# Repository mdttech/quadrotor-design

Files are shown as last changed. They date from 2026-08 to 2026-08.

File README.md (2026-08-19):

# 🚁 Weight Optimized Quadrotor Design
## Design, Optimization, and Fabrication of a Quadrotor







**Conceptual design, optimization, and fabrication of a 300 g payload / 20 min endurance quadrotor**

A MATLAB sizing tool built on Blade Element Momentum Theory coupled to empirical component-weight regressions, taken from mission requirements through parametric optimization, hardware selection, CAD, fabrication, and bench validation.

Course project — AE630, Autonomous Unmanned Aerial Systems.

**Supervisor:** Prof. Abhishek, 
Department of Aerospace Engineering, Helicopter and VTOL Laboratory
Indian Institute of Technology Kanpur, Kanpur 208016, India

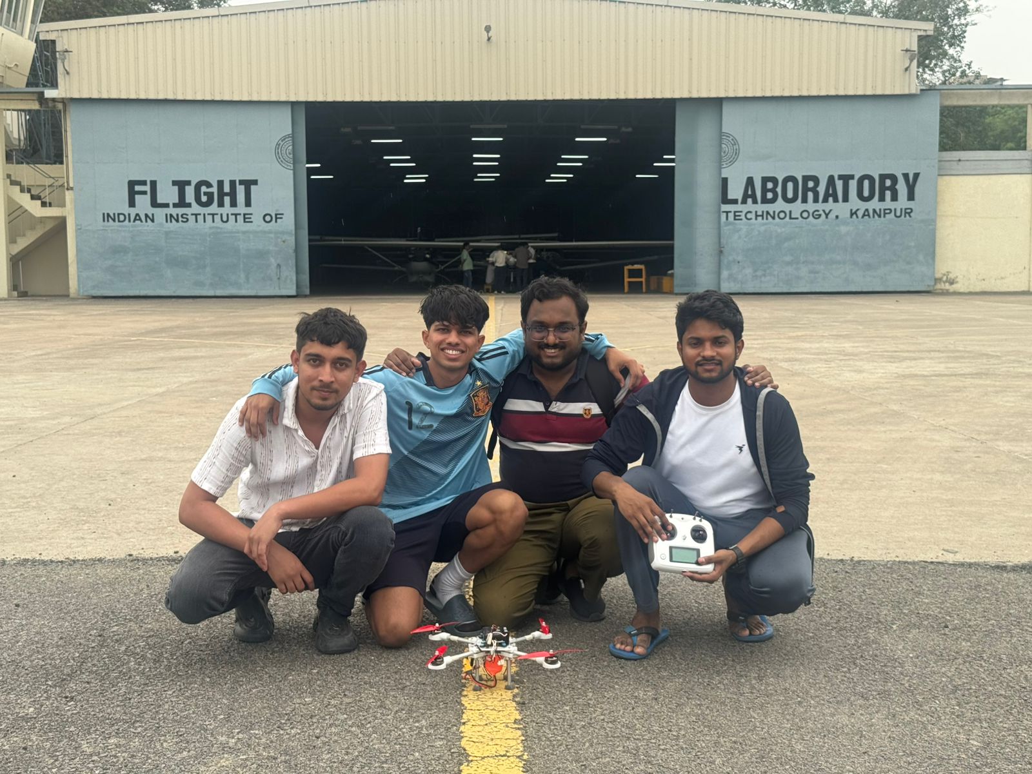
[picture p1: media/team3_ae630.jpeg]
Quadrotor hover test


---

## 🛩️ Mission

| Requirement | Value |
|---|---|
| Payload | 300 g |
| Hover endurance | 20 min |
| Conditions | Sea level, ρ = 1.225 kg/m³ |
| Rotors | Fixed pitch, constant chord |
| Twist distribution | θ(r) = θ₀ − 17r (deg) |
| Target disc loading | 40–90 N/m² |
| Motor efficiency | η_m = 0.80 |

---

## ⚙️ Approach

The design closes on gross takeoff weight through a fixed-point iteration. Every component mass depends on power, power depends on thrust, and thrust depends on the weight you are trying to find — so the loop is run to convergence for every candidate configuration in a parametric sweep.

```
        ┌─────────────────────────────────────────┐
        │  GTOW guess = 3 × payload = 900 g       │
        └────────────────────┬────────────────────┘
                             ▼
              T_hover = W/4  ·  T_design = 2·T_hover
                             ▼
              ┌──────────────────────────────┐
              │  BEMT solver                 │
              │  → C_T, C_P, Ω, P_hover      │
              └──────────────┬───────────────┘
                             ▼
              Battery energy = P_elec × endurance
                             ▼
        ┌─────────────────────────────────────────┐
        │  Empirical weight regressions           │
        │  rotor · motor · ESC · battery · frame  │
        └────────────────────┬────────────────────┘
                             ▼
                  GTOW_new = Σ components
                             ▼
              |ΔW| < 5 g ?  ──no──► relax & repeat
                             │yes
                             ▼
                       converged design
```

**Key modeling note.** With fixed-pitch blades and a linear lift-curve slope, C_T is a property of blade geometry alone and does not vary with rotor speed. This lets the BEMT solver run **once** per geometry at a reference RPM; hover conditions then follow analytically from T ∝ Ω² and P ∝ Ω³. That is what makes a full six-dimensional sweep tractable — thousands of candidate designs converge in seconds instead of hours.

---

## 📐 Design space

Six parameters were swept, with the loop run to convergence at every point:

| Parameter | Range |
|---|---|
| Rotor radius | 0.09 – 0.25 m |
| Root pitch θ₀ | 18° – 26° |
| Aspect ratio (R/c) | 6 – 16 |
| Blades per rotor | 2, 3, 4 |
| Battery cells | 3S, 4S, 6S |
| Motor Kv | 1000 – 3000 |

Note that solidity is **not** independent: σ = N_b·c/πR and AR = R/c give σ = N_b/(π·AR). Only two of the three may be chosen freely.

### Candidate configurations

| | Config 1 | Config 2 | Config 3 |
|---|---|---|---|
| Radius (m) | 0.09 | 0.09 | 0.09 |
| θ₀ (deg) | 26 | 20 | 22 |
| Aspect ratio | 6 | 9 | 8 |
| Blades | 2 | 2 | 2 |
| Cells | 3S | 4S | 4S |
| **GTOW (kg)** | **0.816** | **1.257** | **0.998** |
| Battery (kg) | 0.164 | 0.399 | 0.253 |
| Frame (kg) | 0.225 | 0.338 | 0.274 |
| Hover RPM | 7 849 | 16 717 | 12 157 |
| Kv | 3000 | 1800 | 1300 |
| P_max/motor (W) | 47.3 | 117.9 | 72.3 |

**Config 1** is the mathematical optimum and physically unbuildable — a 12 g motor lacks the stator volume to drive a 7-inch propeller without thermal failure. **Config 2** trades into a punishing 16 700 RPM hover. 
**Config 3** is the realistic middle ground and became the basis for hardware selection.

---

## 🔧 As-built vehicle

Component availability drove the final build away from the theoretical optimum.

| Component | Selection | Qty | Mass |
|---|---|---|---|
| Motor | Emax ECOII-2807, 1300 Kv | 4 | 216 g |
| Propeller | Gemfan Flash 7042 (7.0 × 4.2) | 4 | 24 g |
| ESC | Holybro Tekko32 F4 4-in-1, 50 A | 1 | 13.8 g |
| Battery | Molicel INR21700-P45B 4S1P, 4500 mAh | 1 | 313 g |
| Frame | Custom, aluminium tube arms | 1 | 220 g |
| Avionics & wiring | Pixhawk, GPS, harness | — | 150 g |
| Payload | — | — | 300 g |
| **All-up weight(without payload)** | | | **≈ 937 g** |
| **All-up weight(with payload)** | | | **≈ 1237 g** |

Frame: symmetric X configuration, 3 mm sandwich plates with integrated arm clamps, 12 mm OD aluminium tube arms, gusseted motor mounts. Load path runs motor → mount → arm → clamp → base plate → centre structure.

---

## 📊 Results

Bench thrust testing against the built vehicle:

| Quantity | Predicted (Config 3) | Measured |
|---|---|---|
| Hover efficiency | ≈ 9.8 g/W | 5.41 g/W |
| Hover RPM | 12 157 | 8 440 |
| Hover power (total) | ≈ 102 W | ≈ 228 W |
| Endurance | 20+ min | **≈ 15 min** |

**The vehicle did not meet the 20-minute requirement, and the gap is instructive.**

Three causes account for most of it:

1. **Blade geometry mismatch.** Config 3 models AR = 8 at R = 0.09 m, giving an 11.25 mm chord and σ = 0.080. The Gemfan 7042 actually fitted has roughly a 15–18 mm chord, σ ≈ 0.13. A narrower modeled blade needs higher RPM for the same thrust — which is exactly the 12 157 vs 8 440 RPM discrepancy.

2. **Optimistic aerodynamics.** The BEMT solver uses a constant profile drag coefficient C_d0 = 0.01 and a linear lift curve with no stall. At tip Reynolds numbers of 10⁴–10⁵ this understates profile power, and the chosen θ₀ sits in the high-loading regime where the reference paper explicitly flags BEMT correlation degrading.

3. **Weight growth from procurement.** The intended 41 g motors were unavailable; the 54 g substitutes added 52 g of propulsion mass, which cascades through frame and battery sizing. Final disc loading reached ≈ 120 N/m², well above the 40–90 N/m² band the mission specified — and high disc loading is directly a hover-efficiency penalty.

Net: the sizing model was roughly **1.8× optimistic on hover efficiency**. Closing that gap requires low-Reynolds sectional airfoil tables in place of constant coefficients, and a solidity input matched to the propeller actually procurable rather than a free sweep variable.

---

## 🌀 Propeller Testing

Bench validation of the propeller/motor/ESC combination used on the as-built vehicle, run independently of the full-vehicle thrust test in the Results section above. ESC PWM signal was logged over time at a series of fixed throttle points, mapped to RPM via a calibration curve, and combined with measured thrust/current/voltage to derive mechanical power, Figure of Merit, C_T, and system efficiency across the RPM range.

| Folder | Contents |
|---|---|
| `propeller_testing/data/` | Raw ESC-signal logs (`Log_*.csv`), per-RPM-setpoint time series (`RPM_*.csv`), the averaged summary (`RPM_Summary_Averaged.csv`/`.xlsx`), and the combined performance table (`Final_Data.csv`) |
| `propeller_testing/scripts/` | `plot_logs.py` (ESC signal → RPM calibration and time-series plots) and `plot_final_performance.py` (thrust, power, FOM, C_T, and efficiency vs RPM) |
| `propeller_testing/results/` | Generated plots from both scripts |

Run from inside `propeller_testing/`:

```
python scripts/plot_logs.py
python scripts/plot_final_performance.py
```

| Thrust vs RPM | Figure of Merit vs Thrust |
|:---:|:---:|
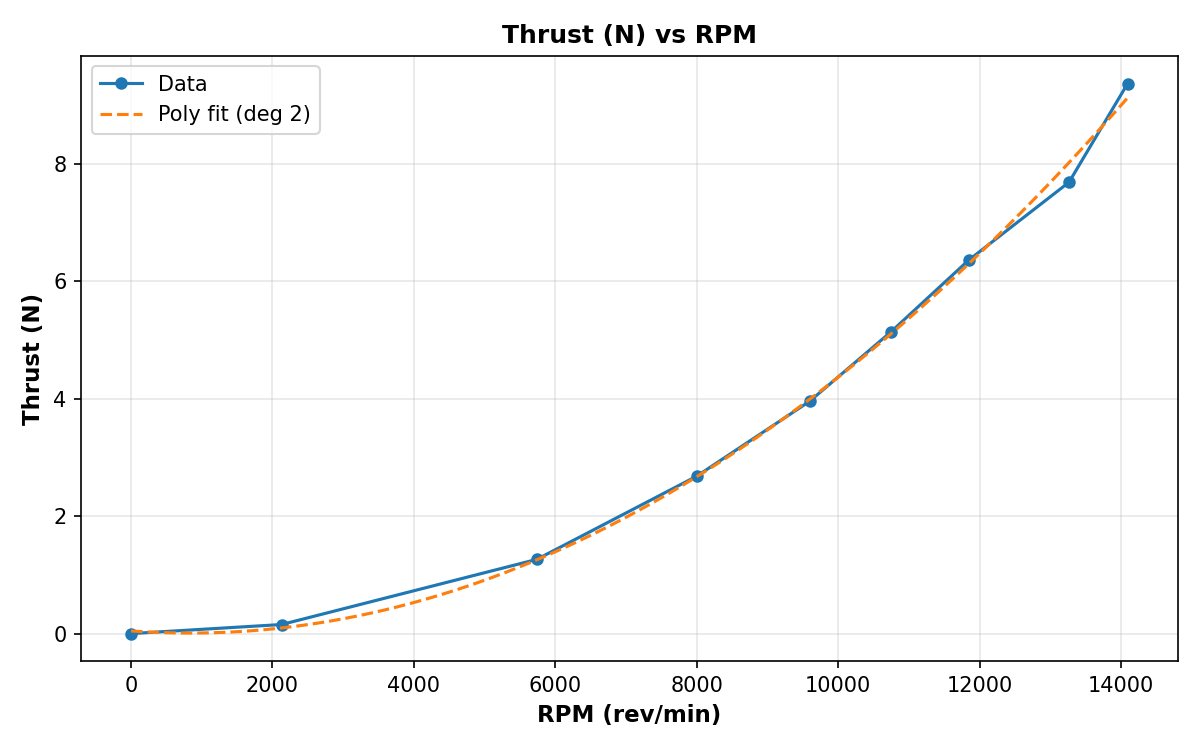
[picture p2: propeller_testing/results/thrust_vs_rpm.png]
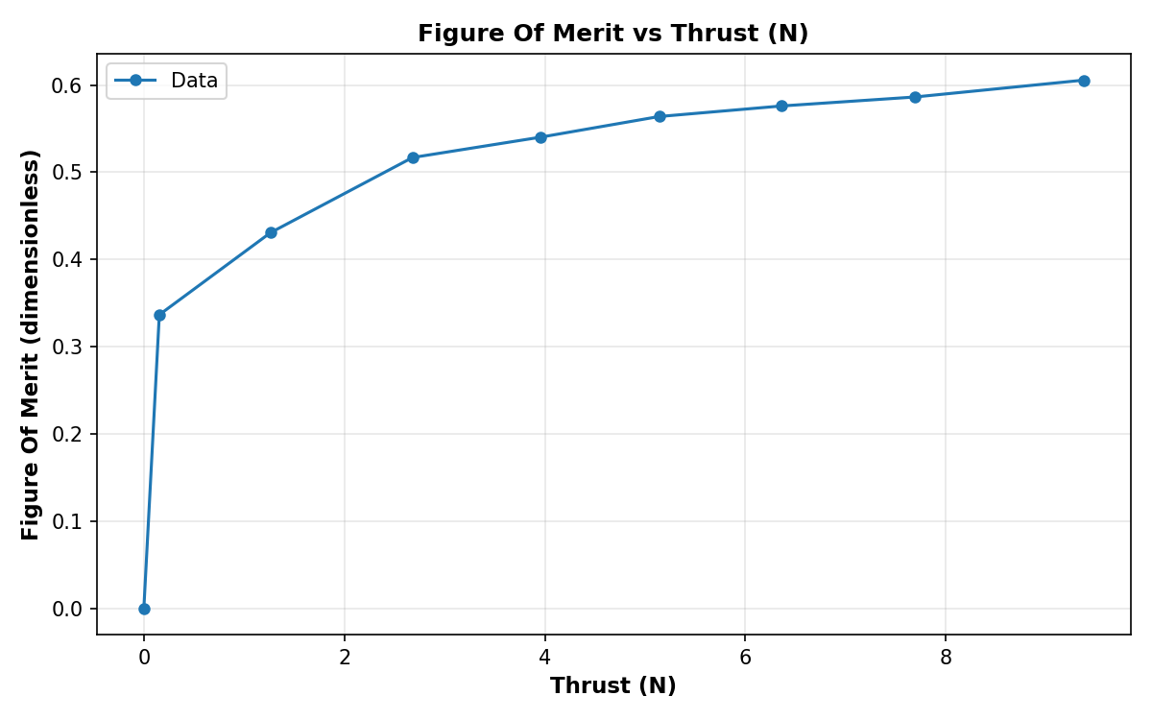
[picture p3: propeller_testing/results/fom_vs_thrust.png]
|  |  |

---

## 📁 Repository structure

```
.
├── src/
│   ├── uav_sizing.mlx                  Weight convergence loop + parametric sweep
│   ├── bemt_gaussian_quad.mlx          BEMT solver, 6-point Gaussian quadrature
│   └── bemt_trapezoidal.mlx            BEMT solver, trapezoidal integration
│
├── results/
│   └── design_Data.csv                 Full converged design table from the sweep
│
├── cad/
│   ├── cad_files/                      Native SolidWorks parts, drawings, STEP exports
│   │   ├── Top_Plate.SLDPRT / .SLDDRW / .STEP
│   │   ├── Bottom_Plate.SLDPRT / .SLDDRW / .STEP
│   │   ├── Part_Arm.SLDDRW
│   │   └── Part_Motor_Mount_final.SLDDRW
│   └── render_images/                  Isometric GIFs and dimensioned views
│       ├── Quadcopter assembly.jpg
│       ├── top_plate_iso.gif           ├── Top Plate.jpg / top plate with dim.jpg
│       ├── bottom_plate_iso.gif        ├── bottom plate.jpg / bottom plate with dim.jpg
│       ├── motor_mount_iso.gif         ├── motor mount.jpg / motor mount with dim.jpg
│       └── arms_iso.gif                └── arms.jpg / arms with dim.jpg
│
├── hardware/
│   ├── BOM.md                          Bill of materials with measured masses
│   └── hardware_sheet.xlsx             Component selection trade study
│
├── propeller_testing/
│   ├── data/                           Raw ESC logs, per-RPM CSVs, averaged summary, combined performance table
│   ├── scripts/                        plot_logs.py, plot_final_performance.py
│   └── results/                        Generated plots (thrust, power, FOM, C_T, efficiency vs RPM)
│
├── media/
│   ├── quadcopter_assembeled_v1.jpg    Assembled vehicle
│   ├── quadcopter_assembeled_v2.jpg
│   ├── team3_ae630.jpeg
│   ├── initial_testing.mp4             Bench and flight test footage
│   ├── testing_without_payload.mp4
│   └── testing_with_payload.mp4
│
├── LICENSE
└── README.md
```

---

## 💻 Running the code

Requires MATLAB R2020b or newer. No additional toolboxes. All files are MATLAB
Live Scripts (`.mlx`) — open them in the MATLAB editor and use **Run** to execute
section by section with inline output and figures.

| File | Purpose |
|---|---|
| `src/uav_sizing.mlx` | Main design tool. Runs the weight-convergence loop across the full parameter sweep and writes `results/design_Data.csv`. |
| `src/bemt_gaussian_quad.mlx` | BEMT solver using 6-point Gaussian quadrature over 10 blade elements. |
| `src/bemt_trapezoidal.mlx` | Same solver using trapezoidal integration (200+ points), for cross-checking the quadrature result. |

**To reproduce the design study:**

1. Open `src/uav_sizing.mlx`
2. Adjust the sweep ranges in the *Parameter Sweep Setup* section if desired
3. **Run All** — the sweep converges every candidate configuration and prints the
   optimal design specification table
4. Results are written to `results/design_Data.csv` and the sensitivity plots are
   generated inline

**To check the BEMT solver independently:** run either `bemt_gaussian_quad.mlx` or
`bemt_trapezoidal.mlx`. Both take the same rotor geometry and return thrust, power,
and the spanwise inflow, pitch, and loading distributions. Agreement between the two
integration schemes confirms adequate spanwise resolution.

> **Note on GitHub rendering:** `.mlx` files are binary and will not preview in the
> browser. Download and open them in MATLAB, or export to `.m` if you want the code
> readable directly on GitHub.

---

## 📸 Media

### CAD table

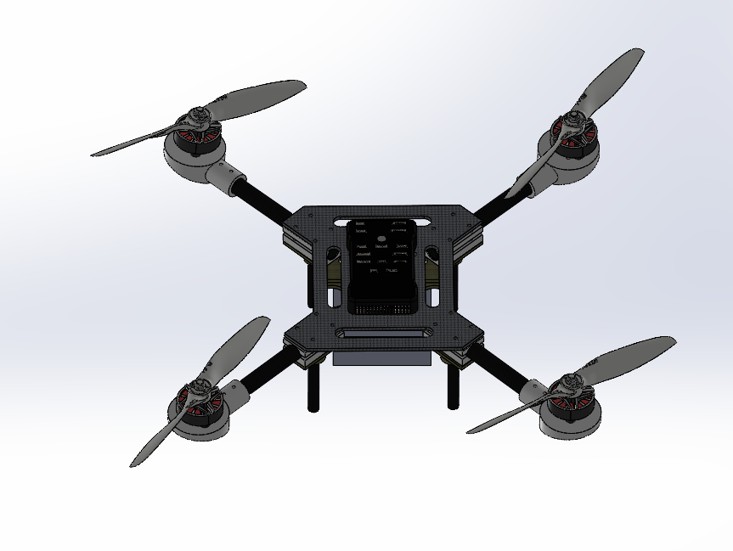
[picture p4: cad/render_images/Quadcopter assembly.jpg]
Quadcopter assembly


| Top plate | Bottom plate | Motor mount | Arms |
|:---:|:---:|:---:|:---:|
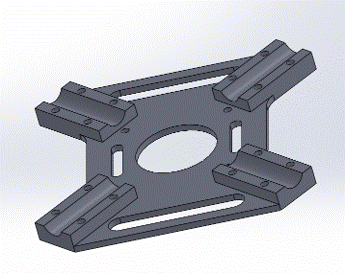
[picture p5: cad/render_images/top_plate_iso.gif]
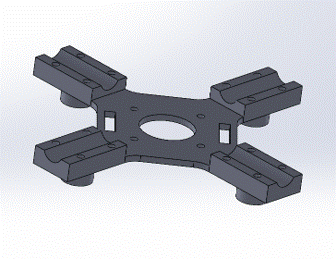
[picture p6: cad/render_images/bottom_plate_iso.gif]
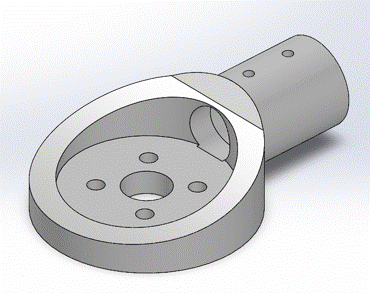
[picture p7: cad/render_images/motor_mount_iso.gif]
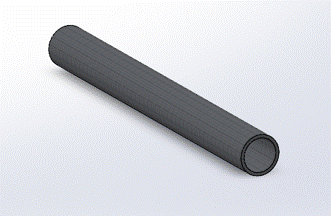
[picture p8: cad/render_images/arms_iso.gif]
|  |  |  |  |

### Media table

| | |
|---|---|
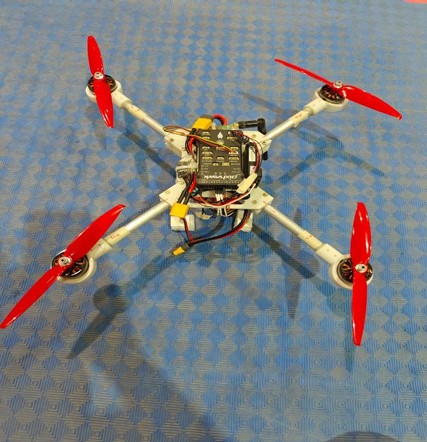
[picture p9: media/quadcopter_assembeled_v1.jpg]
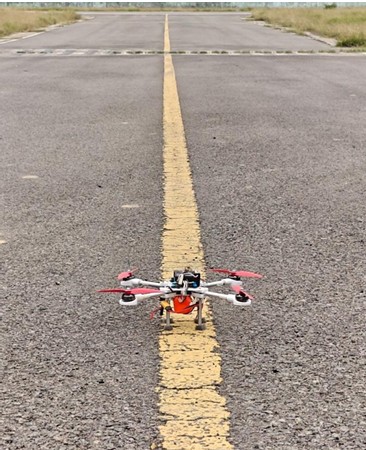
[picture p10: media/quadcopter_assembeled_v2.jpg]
|  |  |
| Assembled vehicle | Alternate view |

Test footage: [initial testing](media/initial_testing.mp4) · [without payload](media/testing_without_payload.mp4) · [with payload](media/testing_with_payload.mp4)

---

## 📚 References

1. Winslow, J., Hrishikeshavan, V., and Chopra, I., "Design Methodology for Small-Scale Unmanned Quadrotors," *Journal of Aircraft*, 2018. [DOI: 10.2514/1.C034483](https://doi.org/10.2514/1.C034483)
2. Leishman, J. G., *Principles of Helicopter Aerodynamics*, 2nd ed., Cambridge University Press, 2006.
3. Bershadsky, D., Haviland, S., and Johnson, E. N., "Electric Multirotor Propulsion System Sizing for Performance Prediction and Design Optimization," AIAA SciTech 2016.

---

## 👥 Team

Group 3 — AE630, Department of Aerospace Engineering, IIT Kanpur

| Name | Roll No. |
|---|---|
| Md Tahseen Aslam | 251010069 |
| Divyansh Singh | 251010064 |
| Magesvar V R | 251010068 |
| Swagat Kumar Jena | 251010073 |
| Pradeep Kumar | 251010071 |

---

## ✍️ Author

**Tahseen Aslam**
M.Tech, Department of Aerospace Engineering (UAS — Autonomy),
Indian Institute of Technology Kanpur




---

## License

Code released under the MIT License. See [LICENSE](LICENSE).
CAD renders, photographs, and the written report are © the authors; reuse by permission.

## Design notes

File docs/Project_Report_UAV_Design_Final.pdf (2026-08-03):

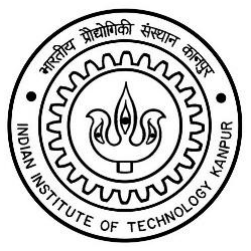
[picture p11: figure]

# Project Report

# Quadrotor Design

Group - 3

Course: AE630
Prepared By:
Name: Md Tahseen Aslam | Name: Divyansh Singh
Roll No.: 251010069 | Roll No.: 251010064
Name: Magesvar V R | Name: Swagat Kumar Jena
Roll No.: 251010068 | Roll No.: 251010073
Name: Pradeep Kumar
Roll No.: 251010071

## Project Title

### Design, Optimization, and Fabrication of a Quadrotor

Abstract
This report details the design, simulation, and fabrication of a custom quadrotor Unmanned Aerial Vehicle (UAV). The primary mission objective is to carry a 300-gram payload while maintaining a hover endurance of at least 20 minutes at sea level conditions. The design process utilized Blade Element Momentum Theory (BEMT) integrated into a MATLAB-based iterative sizing algorithm to converge on a final Gross Take-Off Weight (GTOW). Following the theoretical optimization, specific hardware including high-efficiency brushless motors, propellers, and Lithium-Ion battery was selected and tested. The report concludes with the physical frame fabrication, assembly, and practical validation of the flight time calculations.

### 1. Introduction and Mission Profile

The objective of this project is to develop a mathematically optimized, high-endurance quadrotor. The design parameters are strictly governed by the following mission requirements and environmental assumptions:
- Target Payload:

300 g
- Minimum Hover Endurance:
20 minutes
- Operating Environment: Sea level

ρ = 1.225 kg/m³
- Rotor Constraints: Fixed-pitch, constant chord blades.
- Baseline Disc Loading:
40 to 90 N/m²
- Propulsion Efficiency Assumption:

ηm = 0.80

### 2. Aerodynamic Modeling and BEMT

To accurately predict performance, Blade Element Momentum Theory (BEMT) was employed to calculate the thrust coefficient CTand power coefficient CPof the rotors.

### 2.1. Thrust Requirements

The vehicle must generate enough thrust to hover precisely at the converged GTOW, with a design safety factor yielding a maximum thrust capability of twice the hover requirement:

Thover =

GTOW
4
Tdesign = 2 Thover

### 2.2. Iterative Sizing Algorithm (MATLAB Simulation)

A computer simulation was developed to converge on the final GTOW by balancing the required aerodynamic power with empirical component weight formulas. 2.2.1.Initial Conditions and Inputs
The algorithm initializes with a guessed GTOW of three times the payload:

GTOWinitial = 3 × 300 g = 900 g
The simulation iterates through the following varied inputs:
1. Endurance:
20 minutes (Fixed constraint)
2. Rotor Radius: Varied to maintain disc loading between

40 − 90 N/m²
3. Rotor Operating CT: Adjusted via the root blade pitch angle q0, starting at a baseline of

18∘
4. Solidity & Aspect Ratio: Iterated based on standard propeller geometry.
5. No. of Blades: 2, 3, 4
6. No. of Battery Cells: 4 (4S configuration for optimal voltage/weight ratio). 2.2.2.Convergence Criteria

The BEMT code calculates the necessary hover power, which is then passed to the weight estimation formulas (battery fraction, motor mass, frame mass). The loop updates the vehicle mass until it stabilizes:

∣ GTOWnew − GTOWprevious ∣≤ 5 g
The simulation converged on a final target GTOW of approximately 1.0 kg.

### 3. Hardware Selection

Based on the converged 1kg GTOW and the requirement to lift a 300g payload for 20+ minutes, the components were selected to prioritize thrust-to-watt efficiency.

### 3.1. Theoretical design (BEMT Code Results)

Parameter | Config 1 | Config 2 | Config 3
Radius (m) | 0.09 | 0.09 | 0.09
Theta₀ (deg) | 26 | 20 | 22
Aspect Ratio | 6 | 9 | 8
No. of Blades | 2 | 2 | 2
Cells | 3 | 4 | 4
GTOW (kg) | 0.8164 | 1.2572 | 0.9975
Battery Weight (kg) | 0.1635 | 0.3988 | 0.2528
Motor Weight (kg) | 0.0117 | 0.0320 | 0.0219
Hover RPM | 7849.34 | 16717.46 | 12156.80
Rotor Weight (kg) | 0.00436 | 0.00474 | 0.00463
ESC Weight (kg) | 0.00328 | 0.00603 | 0.00375
Frame Weight (kg) | 0.22468 | 0.33819 | 0.27435
KV Rating | 3000 | 1800 | 1300
Pmax (W) | 47.31 | 117.85 | 72.27
Imax (A) | 4.26 | 7.96 | 4.88

Config - 1
- It represents the absolute mathematical optimum generated by the BEMT code.
- It achieves an incredibly low Gross Take-Off Weight (GTOW) of 0.816 kg and requires only 47.3 W of power to hover. However, this configuration is practically impossible to build for a 300-gram payload mission.
- The simulation suggests using motors that weigh only 12 grams with a highly aggressive 3000 KV rating.
- In the real world, a 12-gram motor lacks the physical stator volume and torque required to spin a 7-inch propeller; attempting to do so would instantly overheat and burn out the motor.

Config – 2
- The BEMT code generated Configurations 2 as solutions closer to practical design parameters.
- Config 2 is a high-RPM, high-weight solution.
- At 1.257 kg GTOW, it demands a massive 0.399 kg battery and requires the motors to spin at a blistering 16,717 RPM to maintain hover, resulting in excessive power draw and poor endurance.
Config – 3
- The BEMT code generated Configurations 3 as solutions closer to practical design parameters.
- Config 3 represents a much better theoretical middle ground.
- It drops the KV rating to a highly efficient 1300 KV and brings the GTOW just under 1 kg.
- While the power draw is an excellent 72.3 W, the motor weight estimate (22 grams) is still slightly too optimistic for off-the-shelf components capable of handling 4S voltages and 7-inch props.

### 3.2. Practical Design

Component | Config 4 (Unavailable) | Config 5 (Selected)
Motor | BrotherHobby Avenger 2806.5 | Emax ECOII-2807
KV Rating | 1300KV | 1300KV
Motor Weight | 41g | 54g
Propeller | HQProp 7x3.5x3 (Tri-blade) | Gemfan Flash 7042 (Bi-blade)
Propeller Weight | 8.8g | 6g
Hover Efficiency | ~5.62 g/W (@310g thrust) | ~5.41 g/W (@300g thrust)
Config – 4: GTOW: 0.950 kg | Motor Weight: 0.041 kg | Power: 172 W
- Configuration 4 was the first practical design selected.
- It successfully translates the theoretical efficiency of Config 3 into real-world hardware. By utilizing actual 41-gram, 1300 KV motors, the total GTOW sits at a highly desirable 0.950 kg.
- The power draw jumps to 172 W, which reflects the true mechanical and electrical inefficiencies of physical components compared to mathematical models.
- This configuration was the optimal real-world choice, offering a lightweight airframe and excellent endurance, but it had to be abandoned due to supply chain issues and component unavailability.
Config – 5: GTOW: 1.100 kg | Motor Weight: 0.056 kg | Power: 136 W

- Configuration 5 is the final, practical build dictated by component availability.
- The most significant shift from Config 4 is the motor weight, increasing from 41 grams to 56 grams per motor.
- This 60-gram total increase in propulsion mass causes a cascading effect on the frame and structural requirements, pushing the final GTOW to 1.100 kg.

### 3.3. Final Selected Hardware (Config 5)

The following components were finalized for the physical drone assembly.

Component | Specifications | Quantity | Total Weight
Motor | Emax ECOII-2807-1300KV (Max Power: 1310W) | 4 | 216g
Propeller | Gemfan Flash 7042 (7.0x4.2, PC Material) | 4 | 24g
ESC | Holybro Tekko32 F4 4in1 (50A Continuous / 60A Burst) | 1 | 13.8g
Battery | Molicel INR 21700-P45B 4S1P (14.8V, 4500mAh, 10C) | 1 | 313g

Estimated Weight:

- Fixed Components:
Motors (216 g) + Propellers (24 g) + ESC (13.8 g) + Battery (313 g) = 566.8 g
- Payload: = 300 g
- Frame: = 220 g
- Miscellaneous Components (estimated from BEMT analysis): = 150 g

Total Estimated AUW

AUW = 566.8 + 300 + 220 + 150 = 1217 g

### 3.4. Estimated Flight Time Calculation:

To verify the 20-minute hover capability, the physical weights of Config 5 components were tallied against the manufacturer's thrust data.
Motor Load Test Data (Emax ECOII-2807-1300KV w/ Gemfan 7042 @ 25.2V)
Throttle State | Current (A) | Thrust (g) | Power (W) | Efficiency (g/W) | RPM
Low / Hover | 2.2 | 300 | 55.44 | 5.41 | 8440
Medium | 4.0 | 500 | 100.80 | 4.96 | 10550
High | 9.3 | 900 | 234.36 | 3.84 | 13960
Maximum | 47.9 | 2190 | 1207.08 | 1.81 | Max

Power Requirement for Hover
To maintain hover at an estimated all-up weight (AUW) of 1217 g, each motor must generate approximately:

= 304.25 g thrust per motor

From the thrust data of Configuration 5, a thrust of 300 g corresponds to an efficiency of 5.41 g/W. Since the required thrust is slightly higher (~304 g), the efficiency will reduce slightly. A conservative estimate of 5.35 g/W is used.
The total hover power required is:

Total Hover Power =

1217
5.35

≈ 227.48 W

Endurance Calculation
The selected battery is a 4S Molicel Li-ion pack with:
Total Energy = 14.8 V × 4.5 Ah = 66.6 Wh Assuming a safe 85% depth of discharge, the usable energy is:

Usable Energy = 66.6 × 0.85 = 56.61 Wh
The estimated flight time is:

Flight Time = (

56.61
227.48) × 60 ≈ 14.9 ≈ 15 minutes

Config - 5 demonstrates strong performance with a maximum thrust capability of up to 2190 g per motor, ensuring sufficient thrust margin for stable flight. However, the increased motor weight and overall system mass result in higher power consumption during hover. As a result, the estimated hover endurance is approximately 17 minutes, which falls short of the target 20-minute requirement.

### 4. Motor Performance Testing 4.1. Methodology

The motor was tested across its throttle range using a variable power supply. Thrust (g), Voltage (V), Current (A), and RPM were recorded.

### 4.2. Results

The empirical data was comp
ared against the MATLAB output. At the required hover thrust: Thover ≈ 250 g per motor the physical test stand demonstrated a mechanical power draw that closely aligned with the BEMT code's predictions, factoring in the assumed motor efficiency:

ηm = 0.80

The practical hover efficiency was recorded at approximately:

7.5 g/W

### 5. Flight Time Calculation and Verification 5.1. Available Energy

Using a 4S Li-Ion pack (14.4V nominal) with a 4500mAh capacity, discharging to a safe 85% depth:

Usable Energy = 14.4 V × 4.5 Ah × 0.85 = 55.08 Wh

### 5.2. Required Hover Power

At a 1000g AUW and a tested efficiency of 7.5 g/W:

Power to Hover =

1000 g
7.5 g/W = 133.33 W

### 5.3. Endurance Validation

Estimated Hover Time = (

55.08 Wh
133.33 W

) × 60 ≈ 24.8 minutes

The theoretical and empirical calculations confirm a safe margin above the 20-minute mission requirement.

### 6. CAD Design

The primary objective is to design a lightweight, structurally robust and modular drone frame capable of flight applications while maintaining a body weight below 1000 gms.

### 6.1. Design Requirements and Constraints: 6.1.1. Propulsion Constraints

- Propeller Size: 7 inch (177.8 mm diameter)
- Minimum propeller clearance was maintained to account for aerodynamic interaction and structural flex.
- A clearance margin of approximately 15–20 mm was considered between adjacent propeller tips to avoid collision during aggressive manoeuvres.

### 6.1.2. Weight Constraints

- Target total weight: <1000 gm

### 6.1.3. Electronics

- Pixhawk: 45mm x 45mm
- ESC: 30.5mm x 30.5mm
- Battery: Zip-Tie using 20mm x 5mm cuts in bottom frame

### 6.2. Overall Design Configuration

The quadcopter follows a symmetric X-frame configuration, ensuring equal thrust distribution and stable flight dynamics.
Key layout decisions:
- Battery mounted centrally for CG alignment
- Pixhawk mounted above center using top plate
- ESC mounted on bottom plate
- Arms arranged symmetrically at 90° from each other
- Each arm clamped to body frame via clamps and 4 30mm M3 bolts and nuts.
- Motors mounted on Motor mounts, connected to the arms coaxially.

### 6.3. Component Design 6.3.1. Bottom Plate

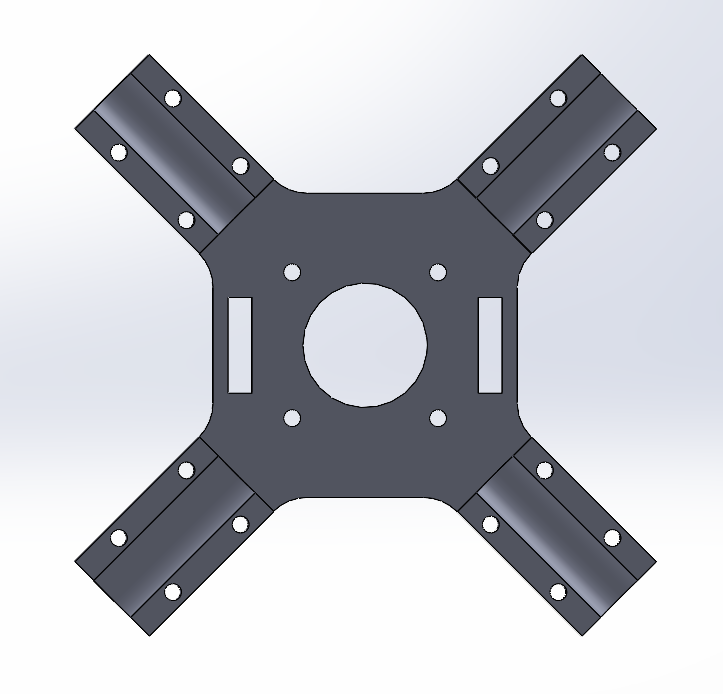
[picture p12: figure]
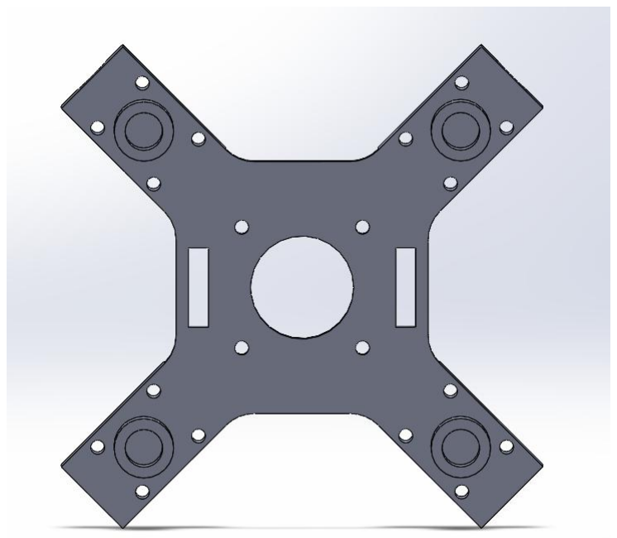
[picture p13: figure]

Figure 2 Bottom Plate (Bottom View) Figure 1 Bottom Plate (Top View)

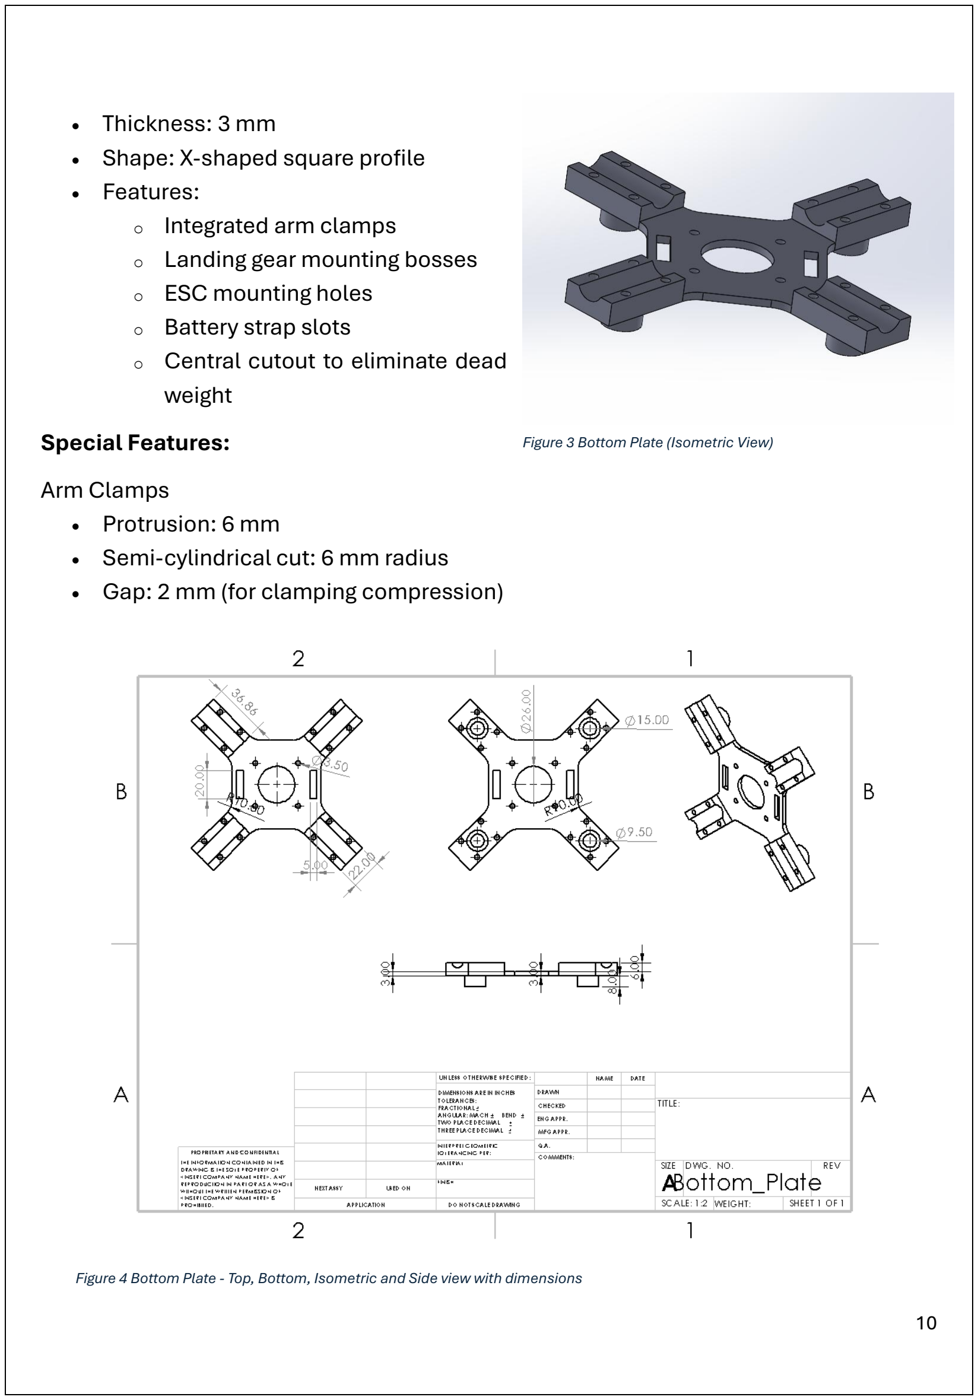
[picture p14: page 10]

- Thickness: 3 mm
- Shape: X-shaped square profile
- Features:
- Integrated arm clamps
- Landing gear mounting bosses
- ESC mounting holes
- Battery strap slots
- Central cutout to eliminate dead weight
Special Features:
Arm Clamps
- Protrusion: 6 mm
- Semi-cylindrical cut: 6 mm radius
- Gap: 2 mm (for clamping compression)

Figure 3 Bottom Plate (Isometric View)

Figure 4 Bottom Plate - Top, Bottom, Isometric and Side view with dimensions

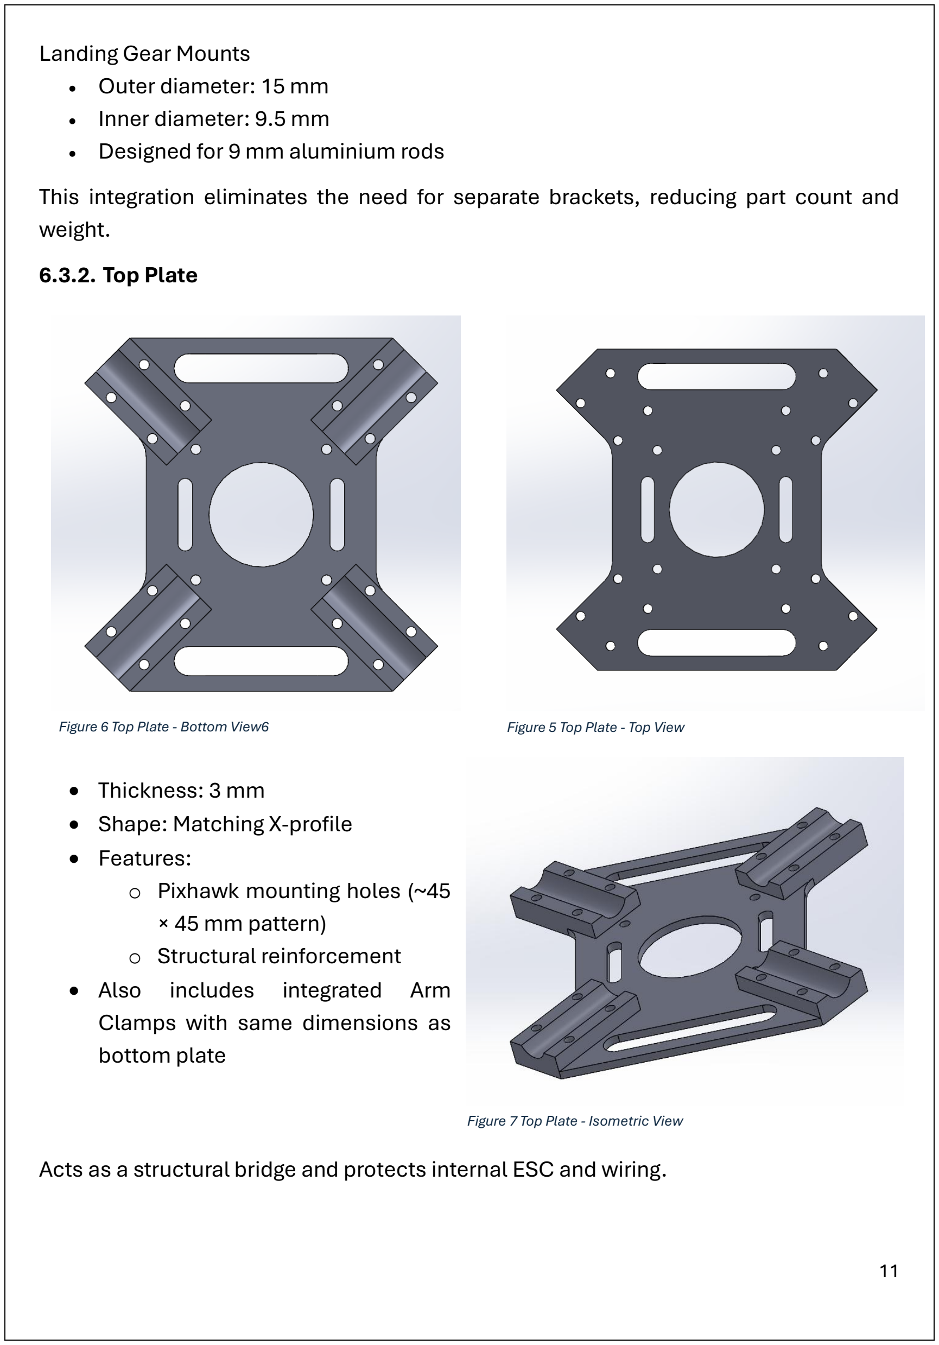
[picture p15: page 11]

Landing Gear Mounts
- Outer diameter: 15 mm
- Inner diameter: 9.5 mm
- Designed for 9 mm aluminium rods
This integration eliminates the need for separate brackets, reducing part count and weight.

### 6.3.2. Top Plate

- Thickness: 3 mm
- Shape: Matching X-profile
- Features:
- Pixhawk mounting holes (~45 × 45 mm pattern)
- Structural reinforcement
- Also includes integrated Arm Clamps with same dimensions as bottom plate

Acts as a structural bridge and protects internal ESC and wiring.

Figure 6 Top Plate - Bottom View6 | Figure 5 Top Plate - Top View

Figure 7 Top Plate - Isometric View

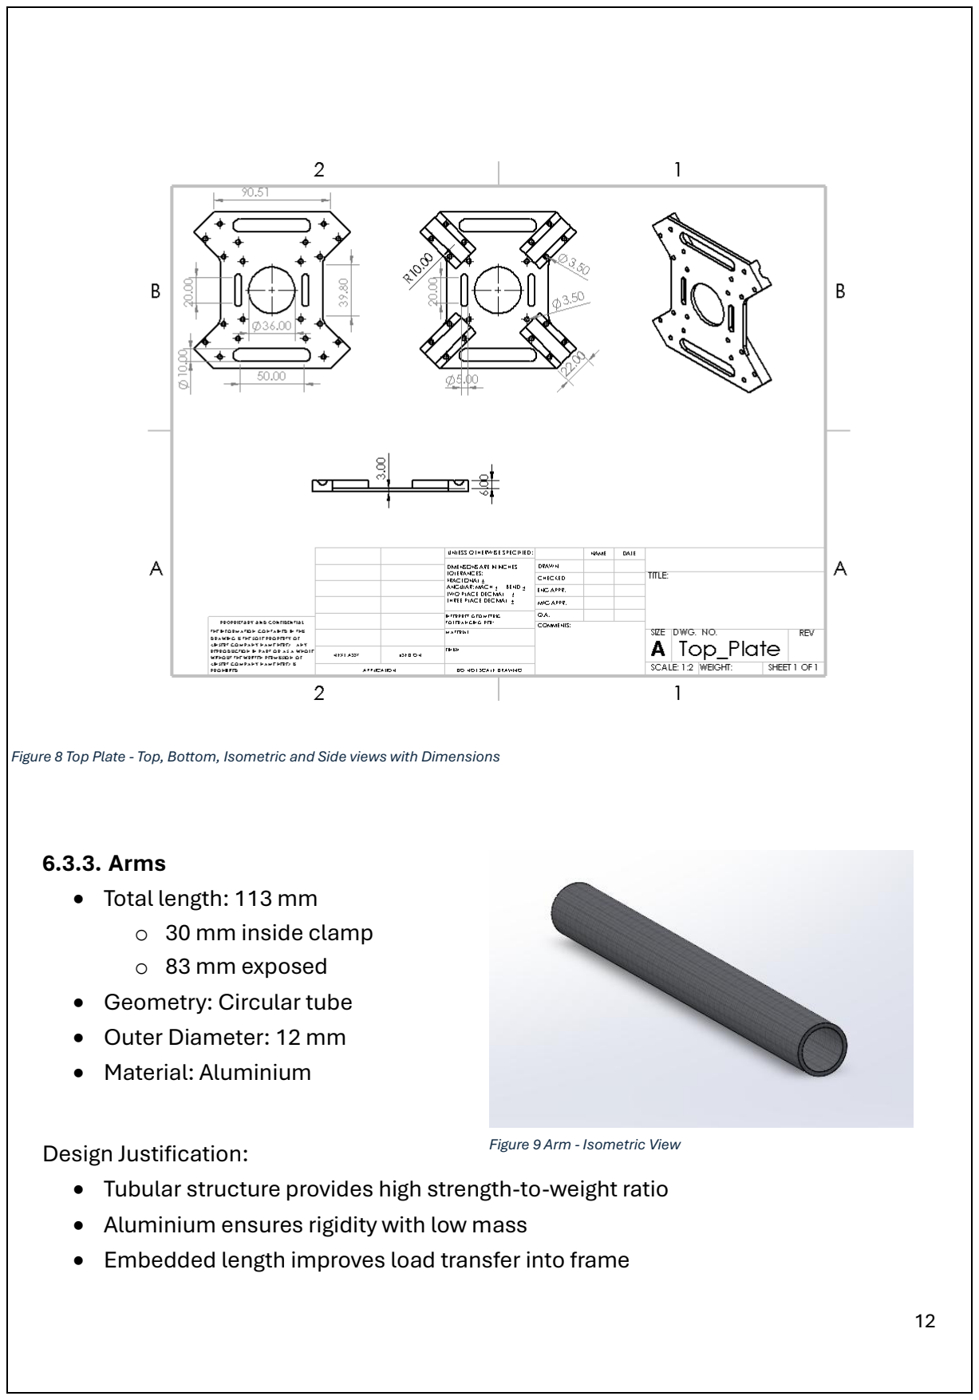
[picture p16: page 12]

### 6.3.3. Arms

- Total length: 113 mm
- 30 mm inside clamp
- 83 mm exposed
- Geometry: Circular tube
- Outer Diameter: 12 mm
- Material: Aluminium

Design Justification:
- Tubular structure provides high strength-to-weight ratio
- Aluminium ensures rigidity with low mass
- Embedded length improves load transfer into frame

Figure 8 Top Plate - Top, Bottom, Isometric and Side views with Dimensions

Figure 9 Arm - Isometric View

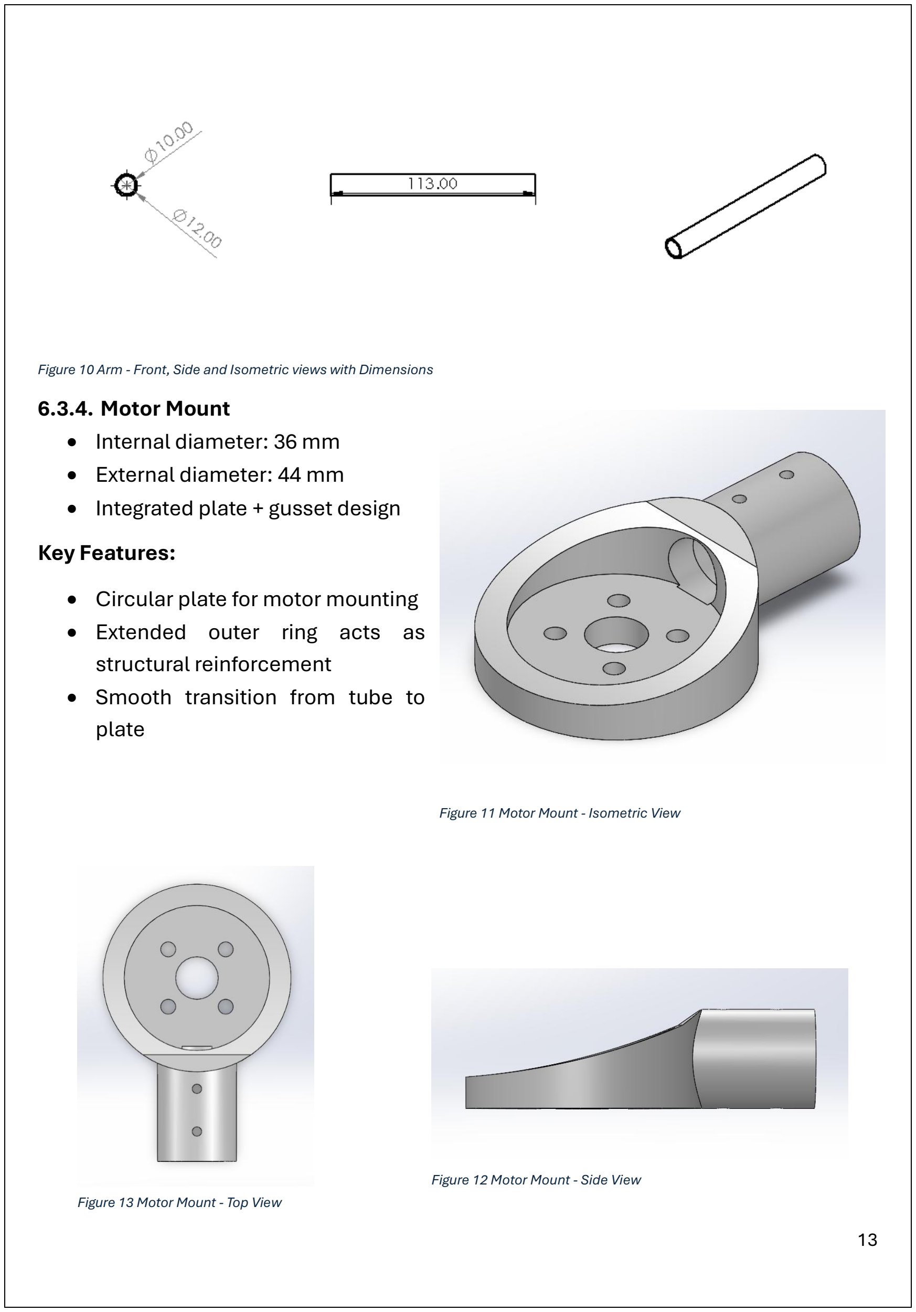
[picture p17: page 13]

Figure 10 Arm - Front, Side and Isometric views with Dimensions

### 6.3.4. Motor Mount

- Internal diameter: 36 mm
- External diameter: 44 mm
- Integrated plate + gusset design Key Features:
- Circular plate for motor mounting
- Extended outer ring acts as structural reinforcement
- Smooth transition from tube to plate

Figure 11 Motor Mount - Isometric View

Figure 12 Motor Mount - Side View Figure 13 Motor Mount - Top View

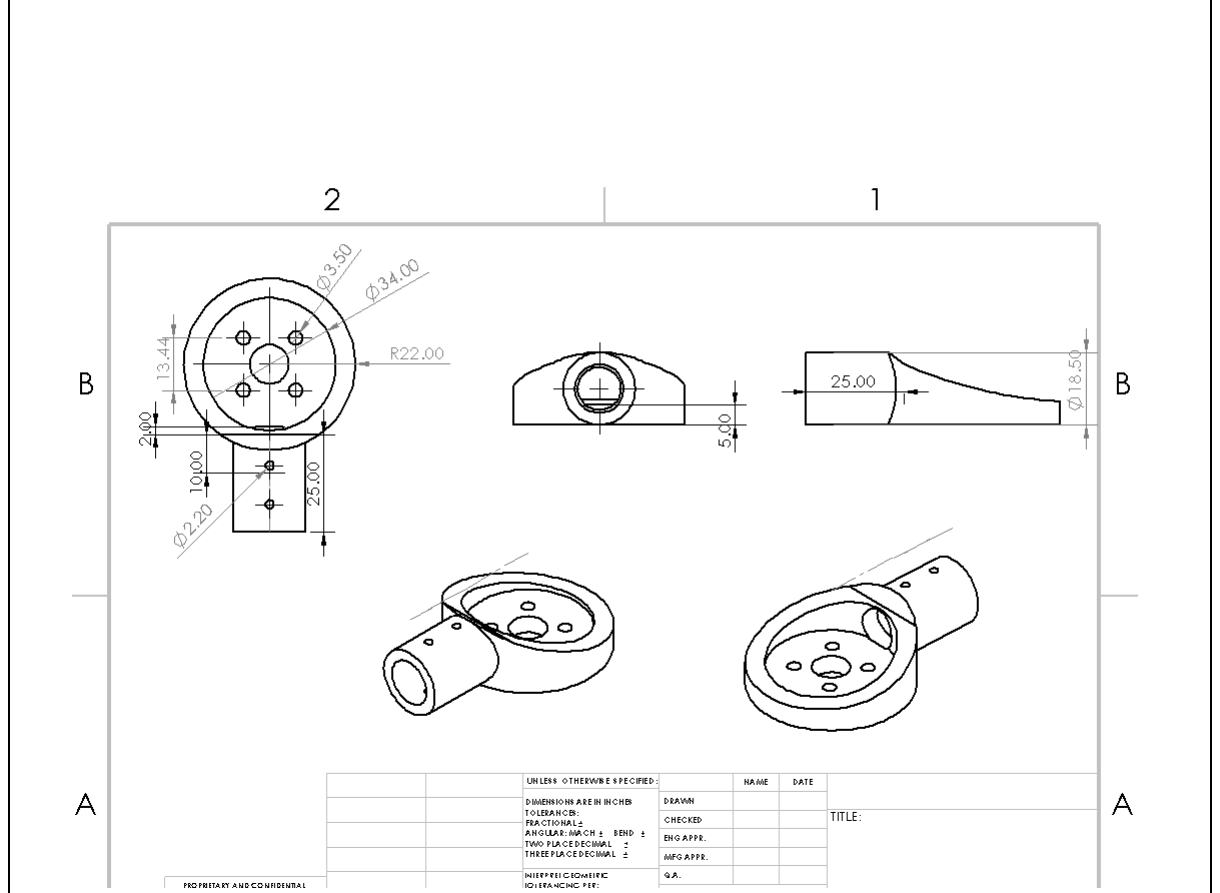
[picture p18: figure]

Design Insight:
The outer diameter extension functions like a radial gusset, distributing bending loads from the motor into the arm.

6.3.5.Frame Size Selection
For 7-inch propellers (177.8 mm diameter), a minimum motor-to-motor spacing of approximately 200–220 mm is required to prevent overlap and allow safe propeller clearance. The chosen arm length ensures:
- Adequate clearance
- Compact structure
- Efficient thrust utilization

Figure 14 Motor Mount - Top, Front, Side, Isometric views with Dimensions

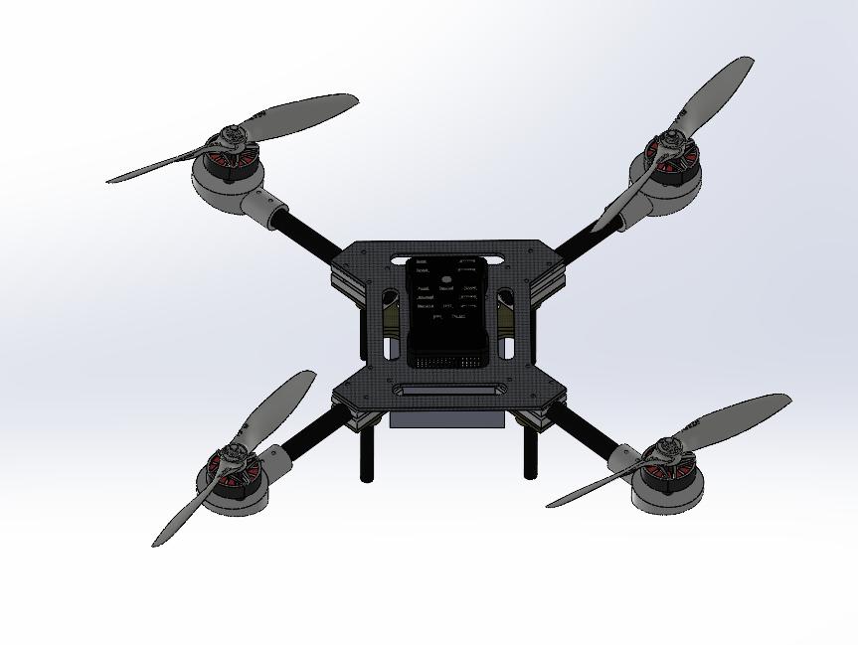
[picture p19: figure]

### 6.3.6. Tube-Based Arm Design

- Reduces weight compared to solid arms
- Improves bending resistance
- Allows internal routing if needed

### 6.3.7. Integrated Clamping System

- Improves alignment accuracy
- Arms are clamped with the base plate
- Reduces number of separate parts.

### 6.3.8. Sandwich System

Top and bottom plates:
- Increase structural rigidity
- Allow internal stacking of ESC and wires
- Improves vibration isolation

Figure 15 Quadcopter Assembly - Isometric View

### 6.3.9. Motor Mount Reinforcement

- Enlarged outer ring acts as load distributor
- Prevents stress concentration at joint
- Improves durability

### 6.4. CAD modelling Approach

The model was developed using SOLIDWORKS. Workflow:
- 2D sketching of base profiles
- Extrusion to define thickness
- Assembly modelling for alignment verification Challenges:
- Zero-thickness geometry during intersections
- Ensuring proper overlap between components

### 6.5. Structural Considerations

Load Path:
The load path in the structure follows:
Motor thrust → motor mount → arm → clamp → base plate → centre structure.
This guided the reinforcement strategy, particularly at the arm-clamp interface and motor mount junction.
Critical Areas:
- Arm-frame interface
- Motor mount – Arm junction
- Clamp compression regions Reinforcement Strategies:
- Circular motor plate (load distribution)
- Gusset design for motor mount
- Tube embedding into frame
- Extra thickness at clamp regions.

### 6.6. Assembly Design

Fasteners Used:
- M3 bolts (25 mm) with nuts: 16 (arm clamping)
- M3 bolts (6 mm): 4 (Pixhawk mounting)
- M3 bolts (3 mm): 20 (16 for motors + 4 for ESC mounting)

### 7. Propeller Performance Calculations:

To evaluate the performance characteristics of the propulsion system, static thrust testing was conducted across the operational envelope of the motor and a 7-inch propeller. The raw telemetry data, including electrical parameters, rotational speed, torque, and thrust, was recorded continuously. To account for sensor noise and transient effects, a steady-state averaging approach was applied. The raw dataset was segmented into distinct, constant-RPM intervals. Within each interval, all data samples were averaged to extract a single, highly reliable steady-state measurement for that specific operational speed. This procedure was repeated incrementally from a low idle speed up to the maximum operational RPM of the motor.
The fixed geometric and environmental parameters used for the non-dimensional analysis of the 7-inch propeller are defined as follows:
- Propeller Radius (R): 0.0889 m
- Disk Area (A): 0.0248 m²
- Air Density (ρ): 1.225 kg/m³

(Standard Sea Level)

### 7.1 Mathematical Formulation

The empirical data was processed to calculate aerodynamic and system efficiencies. The following fundamental equations were utilized:
- Ideal Aerodynamic Power (Pideal): Derived from momentum theory, this represents the theoretical minimum power required to induce the measured thrust
in | hover.

Pideal = √
T

3
2ρA

Where, thrust is measured in Newton.
- Actual Mechanical Power (PMech.): The true aerodynamic power delivered to the propeller, calculated using the measured motor torque (τ) and angular velocity (Ω).

PMech. = τ Ω
- Figure of Merit (FM): A measure of the propeller's hover efficiency, comparing the ideal power to the actual mechanical power consumed.

FM =

Pideal

PMecℎ.
- System Efficiency (ηsys.): The overall efficiency of the motor and Electronic Speed Controller (ESC) combination, representing the conversion of electrical input power to mechanical output power.

ηsys. =

PMecℎ.
V.I
- Thrust Coefficient (CT): The non-dimensionalized parameter characterizing the propeller's thrust-generating capability, calculated for the static condition (J=0).

CT =

T
ρA(ΩR)

2

### 7.2 Graphical Analysis of Performance Metrics

I. Thrust vs. Rotational Speed (RPM): This plot visualizes the fundamental lifting capability of the rotor system. The experimental data closely follows the theoretical quadratic relationship, where thrust is proportional to the square of the angular velocity. This confirms predictable control mapping between motor speed commands and physical force generation.

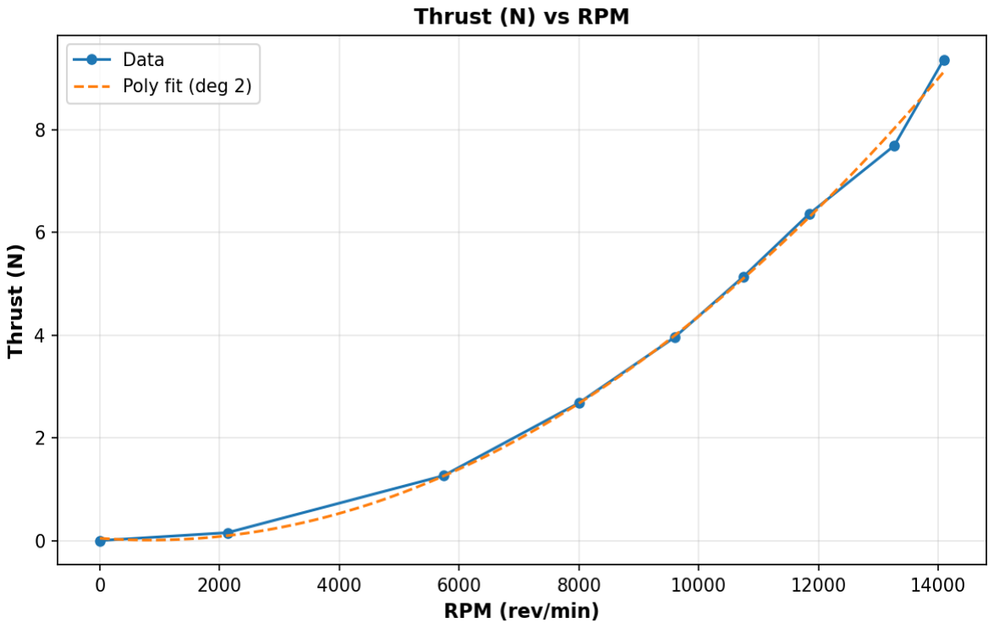
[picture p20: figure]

Figure 16 Thrust (N) vs RPM plot

II. Mechanical Power vs. Rotational Speed (RPM): This plot details the mechanical energy demanded by the propeller to displace the surrounding air mass. As predicted by aerodynamic theory, the power curve exhibits a cubic growth rate. The steep escalation at higher RPMs illustrates the rapidly increasing energy cost required to generate peak thrust.

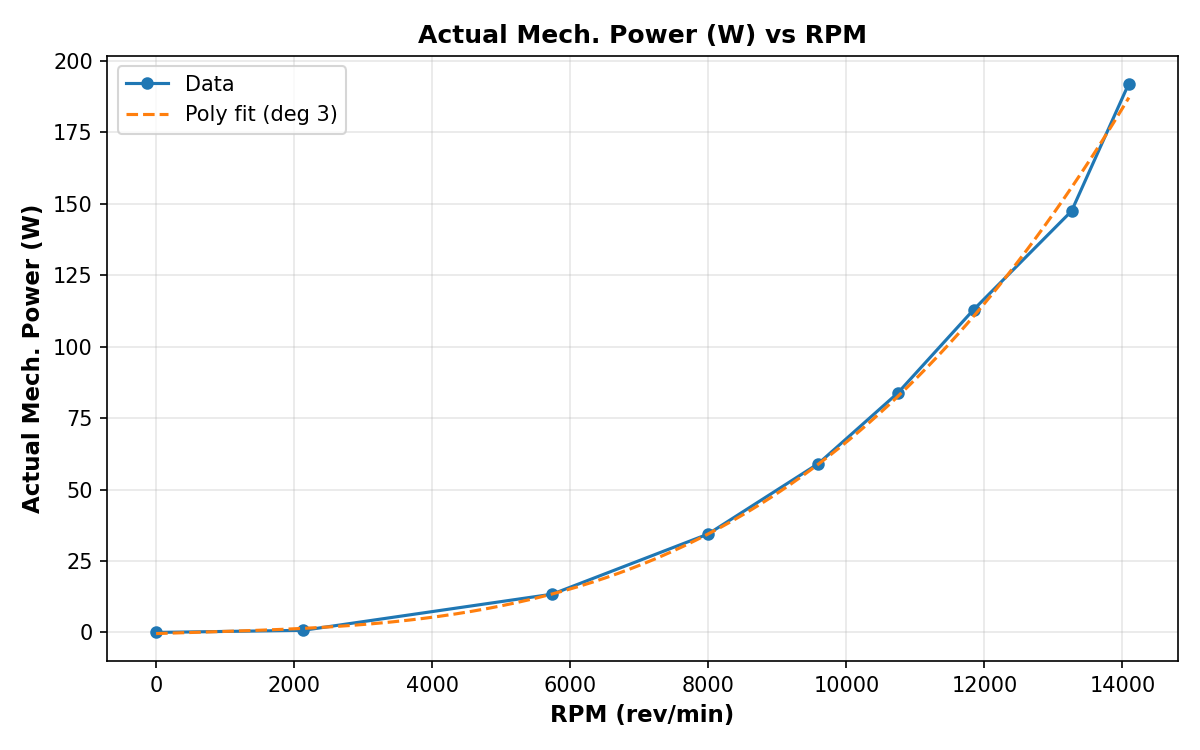
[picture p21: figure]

III. Figure of Merit vs. Thrust: This analysis illustrates how the aerodynamic efficiency of the propeller scales with the applied load. The curve demonstrates a low efficiency at minimal thrust, rising steadily to a peak efficiency (the optimum hover state) before plateauing or slowly degrading. This optimal zone indicates the

Figure 17 Actual Mech. Power (W) vs RPM


Figure 18 Figure of Merit vs Thrust (N)

most efficient thrust-to-weight ratio for sustained hovering flight.

IV. System Efficiency vs. Rotational Speed (RPM): This plot evaluates the electromechanical conversion efficiency of the motor-ESC unit. The data reveals a rapid rise in efficiency at lower RPMs, stabilizing at a peak operating band, and eventually displaying a slight decay as resistive heating takes place.

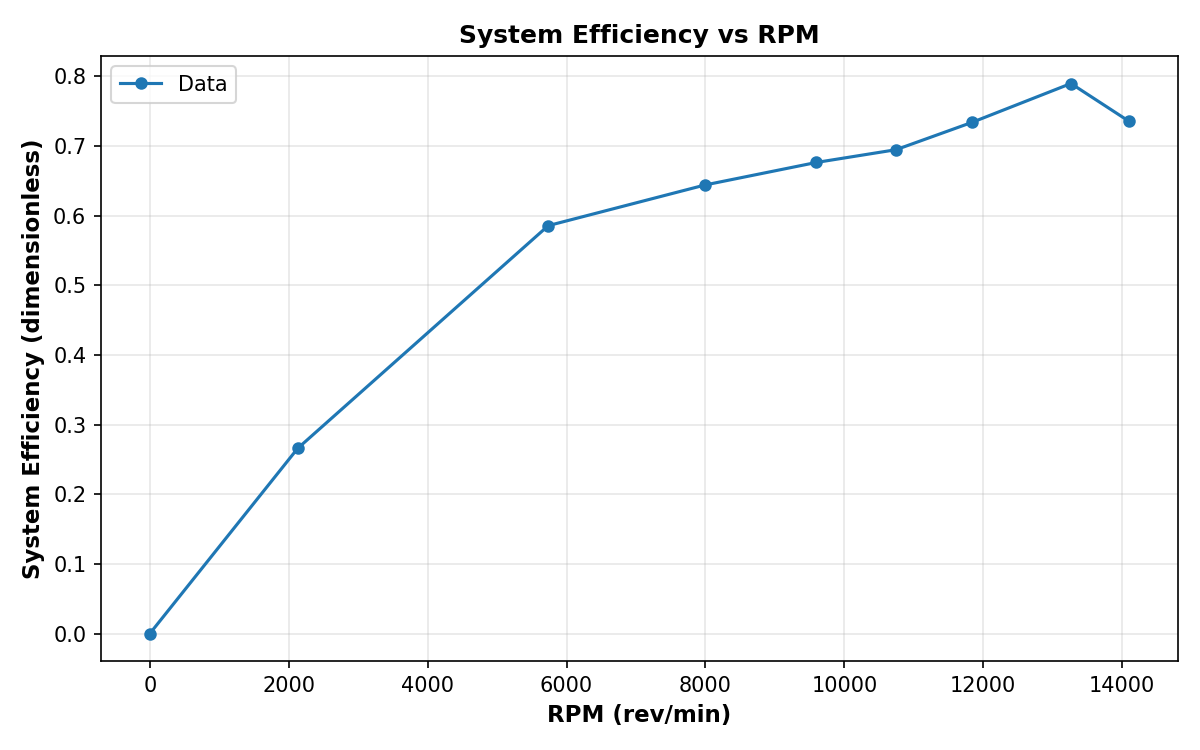
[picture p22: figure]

V. Thrust Coefficient (CT) vs. Rotational Speed (RPM): This graph plots the non-dimensional thrust coefficient across the tested speed range. At lower RPMs, the CT values display slight variance due to low Reynolds number effects and less stable flow attachment. However, as the rotational speed increases, the curve flattens into a steady horizontal line.

Figure 19 System Efficiency vs RPM

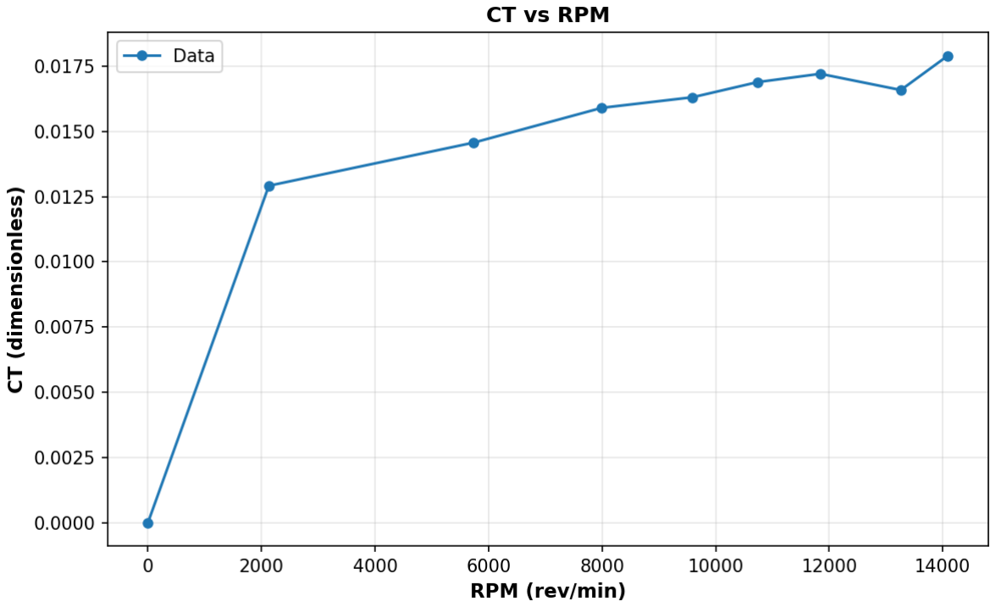
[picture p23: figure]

Figure 20 Thrust Coefficient vs RPM

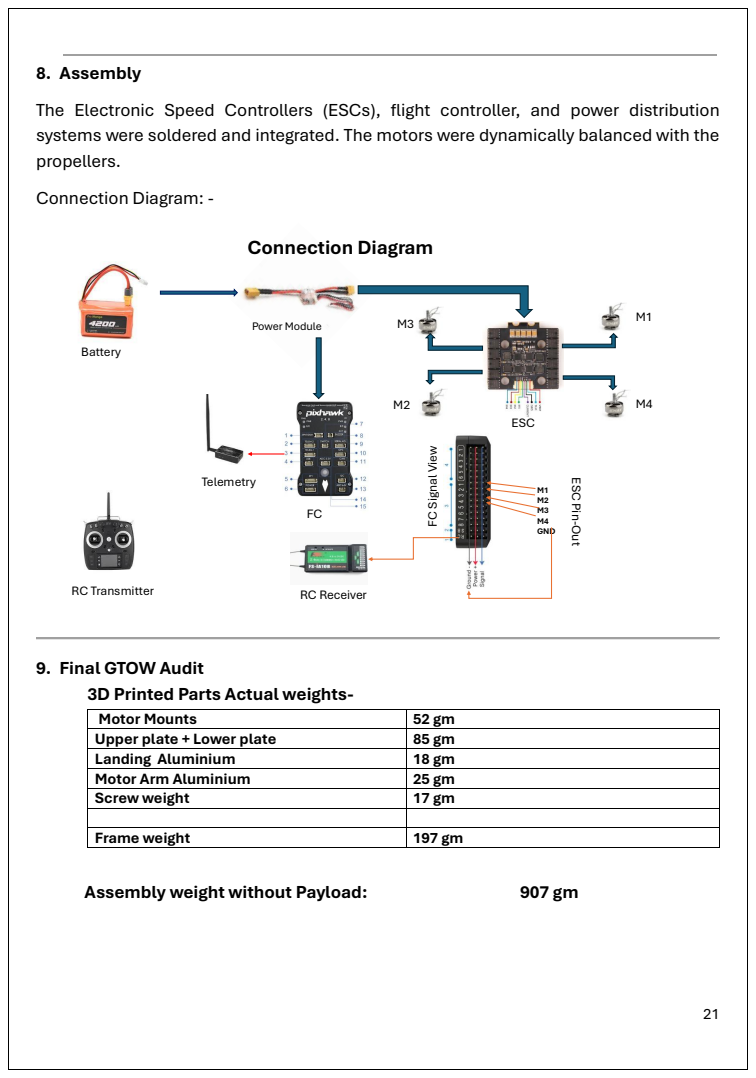
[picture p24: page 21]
Frame weight; Assembly weight without Payload:; Power Module; Battery; M1 M2 M3 M4 GND; ESC; RC Receiver; Telemetry; Connection Diagram; RC Transmitter

8. Assembly
The Electronic Speed Controllers (ESCs), flight controller, and power distribution
systems were soldered and integrated. The motors were dynamically balanced with the
propellers.
Connection Diagram: -

FC Signal View

ESC Pin-Out

9. Final GTOW Audit
3D Printed Parts Actual weights-

Motor Mounts | 52 gm
Upper plate + Lower plate | 85 gm
Landing Aluminium | 18 gm
Motor Arm Aluminium | 25 gm
Screw weight | 17 gm

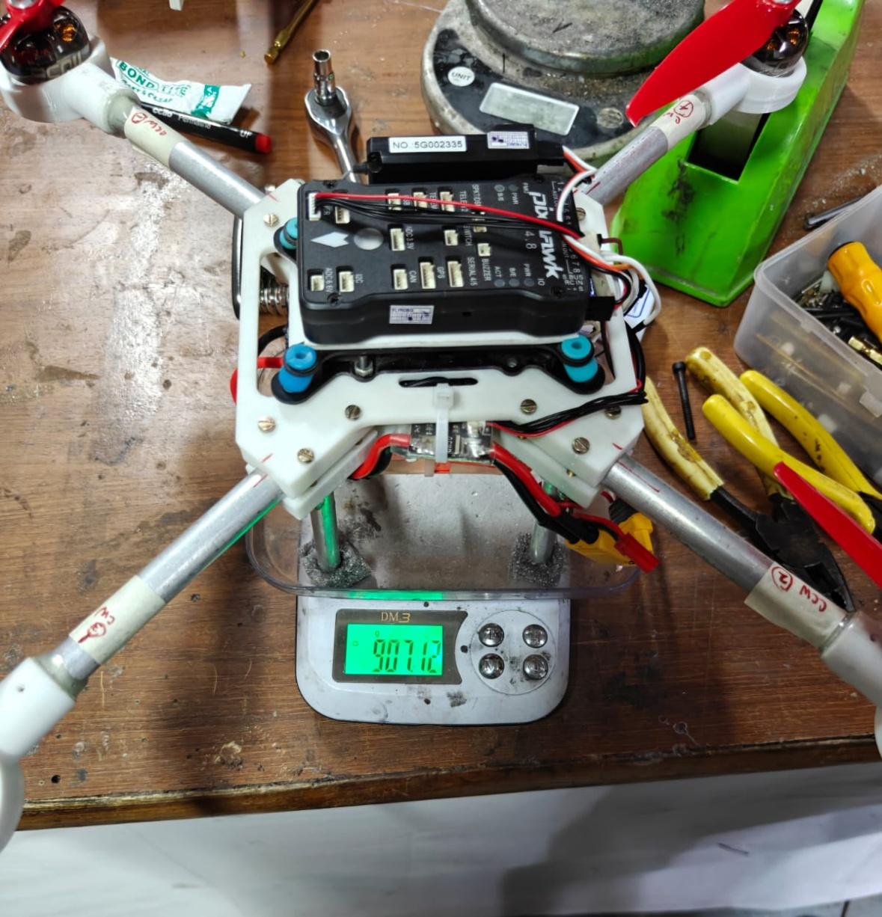
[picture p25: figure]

Figure 21 Final Assembly weight without Payload weight
Final Weight With Payload: | 1207 gm
The fully assembled drone, including the 300g payload and 4S battery, was weighed. The physical All-Up Weight (AUW) came to 1207 gm, which is 200 gm more than the 1kg GTOW predicted by the computer simulation.

### 10. Final Field Testing

- The first flight testing we did inside the Helicopter Lab was without the payload weight.
- It was a very successful flight, and we achieved all our requirements.

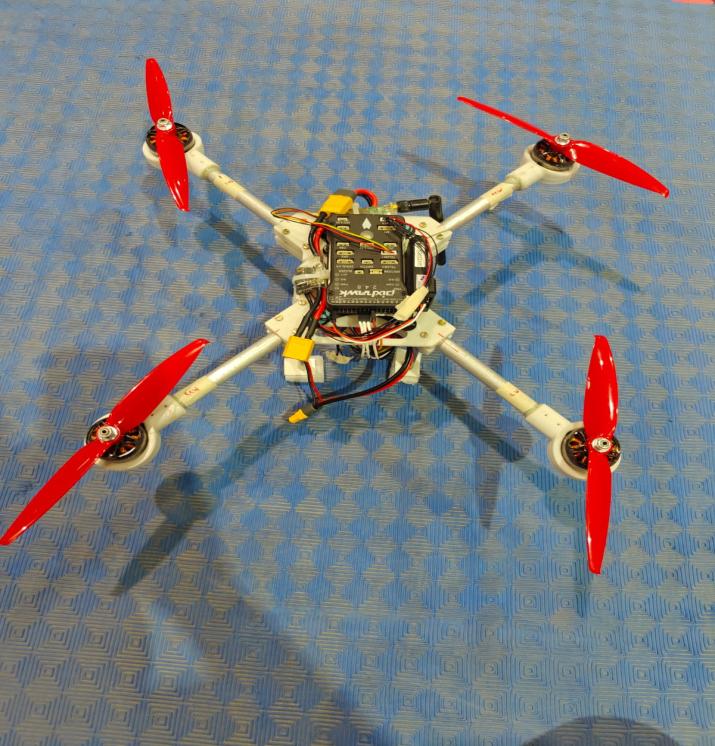
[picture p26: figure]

Figure 22: Heli-Lab Testing Setup

- After successfully light testing in the heli-lab, we went to the IIT Kanpur airstrip for our final testing.
- There, we conducted two test cases-
- Without Payload-

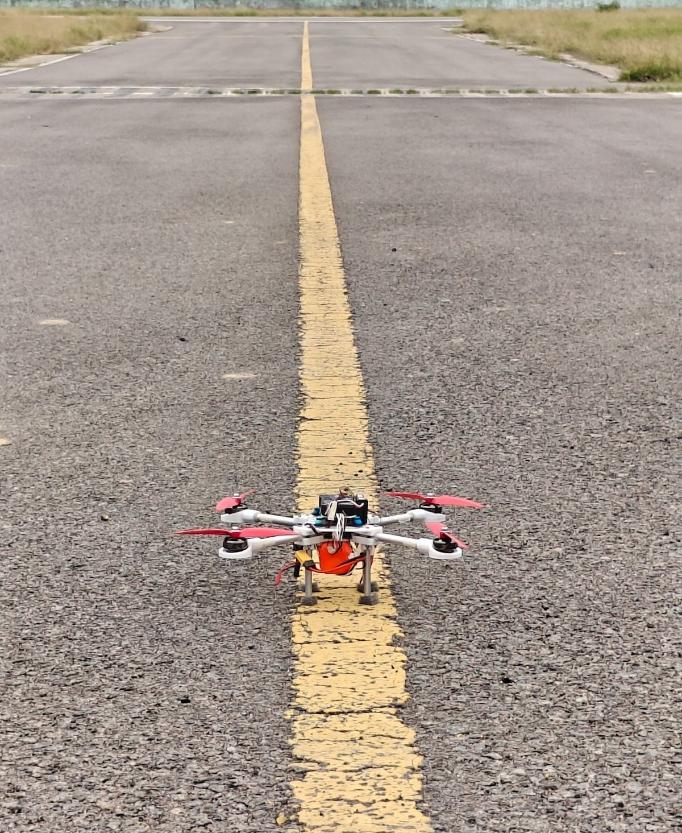
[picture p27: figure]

Figure 23: On the Airstrip Without Payload

- The test flight was successful, and we achieved all requirements.
- Flight Testing with Payload-

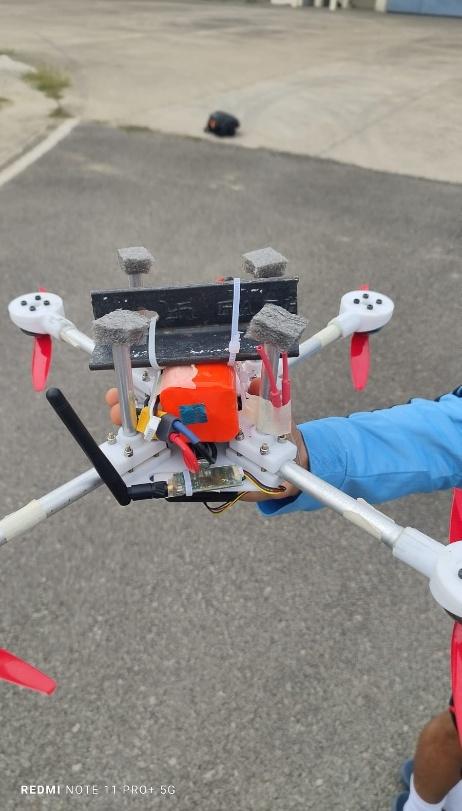
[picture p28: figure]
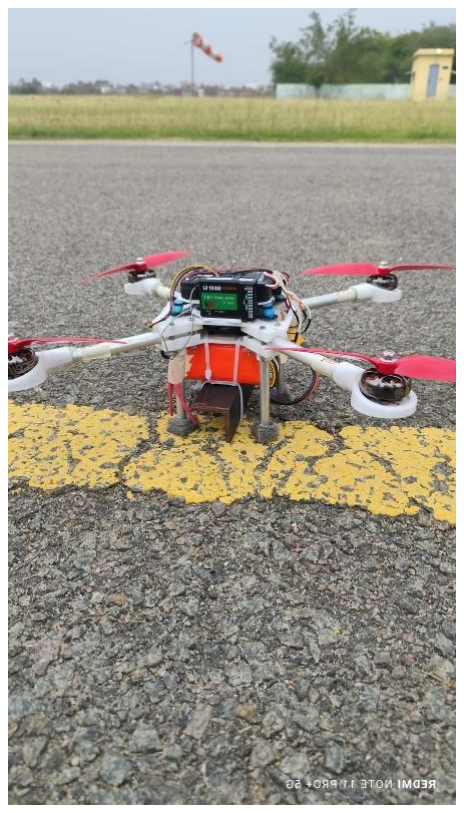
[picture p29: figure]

- The flight testing was successful with the payload, and we achieved all requirements.

Conclusion
The project successfully demonstrated the end-to-end design of a mission-specific quadrotor. By leveraging BEMT and an iterative weight-convergence algorithm, the theoretical framework accurately predicted the required component sizing. The physical assembly and subsequent motor testing validated the simulation, resulting in a mass of less than 1 kg. Fully capable of carrying a 300g payload for nearly 14 minutes, and without payload, nearly 18 minutes.
Figure 24: Payload Attachment | Figure 21: Testing with Payload

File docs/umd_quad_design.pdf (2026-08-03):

# Design Methodology for Small-Scale Unmanned Quadrotors

Justin Winslow,∗ Vikram Hrishikeshavan,† and Inderjit Chopra‡ University of Maryland, College Park, Maryland 20742

DOI: 10.2514/1.C034483 (http://dx.doi.org/10.2514/1.C034483)

The increasing usage of low-Reynolds-number (10,000–100,000 tip Reynolds number) scale quadrotors for civilian and military applications provides the impetus for the development of reliable design methodologies. At present, there is limited understanding of how to accurately size quadrotor components for a specific mission. These components include the rotors, motors, speed controllers, batteries, and airframe. However, empirical relationships may be derived for these components based on manufacturer data. The present research identifies the key factors driving vehicle weight and provides a framework for implementing these factors in a micro air vehicle design tool. Starting from basic rotor parameters (such as radius, solidity, and airfoil section) and an initial gross takeoff weight estimate, a blade element momentum theory framework coupled with computational-fluid-dynamics-generated sectional airfoil tables provides an acceptable estimate of low-Reynolds-number rotor power and torque for required thrust. The aerodynamic power and torque along with desired flight time and speed drive the weights of the quadrotor components. The proposed sizing tool has been validated against a series of existing quadrotors with 30–1000 g gross takeoff weights. Current results show that individual weight groups can be predicted generally within a 10% deviation and the gross takeoff weight of each vehicle is predicted within a 4% variation.

Nomenclature
C | = | battery capacity
dBL | = | brushless motor diameter
dDC | = | brushed direct-current motor diameter
I | = | electric current
Icont | = | maximum sustainable current
Imax | = | maximum burst current
Kv | = | motor speed constant
lBL | = | brushless motor length
lDC | = | brushed direct-current motor length
mA | = | airframe mass
mB | = | battery mass
mBL | = | brushless motor mass
mDC | = | brushed direct-current motor mass
mR | = | rotor mass
Nb | = | number of blades
P | = | rotational power
Qmax | = | maximum motor torque
R | = | rotor radius
S | = | battery cells in series
σ | = | solidity; Nbc∕πR
I. Introduction
ROTARY-WING micro air vehicles (MAVs) are envisioned to have a large impact in civilian and military scenarios, primarily due to their hovering capability. The small size and hovering ability of rotary-wing MAVs make them particularly attractive for reconnais-sance in confined, indoor environments and hazardous areas. Multirotor MAVs, such as quadrotors, are a subset of rotary-wing MAVs that forgo tail rotor and swashplate control for multiple coplanar rotors. The quadrotor configuration is preferred over other small-scale rotary-wing vehicles because it is mechanically simple in design and flight control. Given the recent emergence of quadrotor MAVs, the guidelines for quadrotor design have been mostly ad hoc and are not based on rigorous weight models, as is the case for full-scale rotorcraft. Limited attempts have been made by research institutions to develop sizing methods for MAVs. The ETH Zurich method uses an active database lookup function for components for each sizing iteration [1]. The National Technical University of Athens developed a parameterization method similar to the present study [2]. However, this method was limited because it primarily depended on only the physical lengths of each component. More recently, the Georgia Institute of Technology also developed a parameterization-based method [3]. Unlike the present research, this method was limited to brushless motors and did not characterize brushed motors or speed controllers commonly used on smaller [less than 100 g gross takeoff weight (GTOW)] quadrotors. Furthermore, a method for obtaining and validating edgewise flight performance characteristics, which are important for sizing quadrotors for different mission requirements, was not addressed. A popular online tool for MAV design is eCalc [4]. However, this design program is based on manual user selection of specific vehicle components to estimate performance. Contrary to eCalc, the proposed methodology determines vehicle component requirements based on mission parameters such as endurance, flight speed, and payload capacity. Conventional sizing methods for large-scale rotary-wing vehicles have been well described by Tishchenko, Boeing–Vertol, and the Research and Technology Laboratories of the U.S. Army Aviation Research and Development Command [5–7]. These methods are intended to be used for vehicles with fuel-based engines. As such, the required fuel weight fraction is iteratively factored into the total vehicle weight based on the required power and mission segments. Modern design methods pertaining to electric propulsion for large-scale vertical takeoff and landing concepts have also been studies [8–10]. However, conventional sizing trends may not be completely applicable to MAVs due to their scale and different propulsion requirements. Furthermore, weight groups accounted for in conventional helicopter sizing include the main rotor hub and tail rotor, which are not present in a quadrotor. However, the general methodology used to derive sizing relations is applicable at MAV scales. Specifically, multivariable linear regression is used by the Research and Technology Laboratories to derive empirical sizing equations. This method has been shown to consistently yield accurate weight predictions for a range of large-scale helicopters [5]. Therefore, the aim ofthe present researchisto derive a similar sizing methodology that is now applicable to small-scale multirotor vehicles.
This paper describes the development and application of a design methodology for small-scale rotary-wing MAVs. First, the primary quadrotor components are introduced; and the empirical trends,

Presented as Paper 2017-0014 at the 55th AIAA Aerospace Sciences Meeting, Grapevine, TX, 09–13 January 2017; received 22 March 2017; revision received 31 August 2017; accepted for publication 13 September 2017; published online 21 November 2017. Copyright © 2017 by the American Institute of Aeronautics and Astronautics, Inc. All rights reserved. All requests for copying and permission to reprint should be submitted to CCC at www.copyright.com; employ the ISSN 0021-8669 (print) or 1533-3868 (online) to initiate your request. See also AIAA Rights and Permissions www.aiaa.org/randp.
*Graduate Research Assistant, Department of Aerospace Engineering, Alfred Gessow Rotorcraft Center. Student Member AIAA. †
Assistant Research Scientist, Department of Aerospace Engineering, Alfred Gessow Rotorcraft Center. Senior Member AIAA. ‡
Distinguished University Professor and Director, Department of Aerospace Engineering, Alfred Gessow Rotorcraft Center. Fellow AIAA.
Article in Advance | / | 1

JOURNAL OF AIRCRAFT

Downloaded by INDIAN INSTITUTE OF TECHNOLOGY on December 10, 2017 | http://arc.aiaa.org | DOI: 10.2514/1.C034483

which drive their weights, are presented. These trends have been quantified and organized in multivariable regression equations. The means of calculating and validating rotor power in hover and forward flight are also included. Finally, the schematic of the complete sizing algorithm and the validation of its results is presented.

II. Quadrotor Components and Weight Trends The following section describes the general quadrotor component groups in order of sizing consideration: rotors, motors, electronic speed controllers (ESCs), batteries, and the airframe. The general layout of these components is shown in Fig. 1. Additionally, data are presented from measurements and manufacturer specifications, which show evidence of correlation between the component weight and key design parameters (e.g., rotor radius, power output, and energy storage). Figure 2 provides the general range of quadrotor gross takeoff weights and disk loadings (GTOW/total rotor area) that are considered in the present study. The points in Fig. 2 represent quadrotors that have been disassembled and weighed for the current study. The scatter of data shows the current adoption of an ad hoc design methodology in the development of small-scale quadrotors.

A. Rotors
An aerodynamic analysis of rotors will yield the approximate rotor design parameters for a required disk loading, range, and endurance objective. Because these design parameters (such as rotor radius, blade chord, and number of blades) influence the rotor weight, they can be correlated to the rotor mass as shown in Fig. 3.
Figure 3 represents a sampling of polystyrene and carbon-fiber rotors with various radii, solidities, and numbers of blades. These trends show that, for a variety of microrotors, the radius and blade solidity are key sizing parameters.
B. Motors
There are two types of electric dc motors commonly used in quadrotor MAVs: brushless dc (BLDC) motors and brushed motors. For the majority of larger quadrotors (greater than 100 g GTOW), brushless motors tend to be the more popular choice. This is mainly because their operating principle keeps internal friction low and efficiency high. In BLDC motors, the stator is composed of wire coils to induce magnetic fields, whereas the rotor holds permanent magnets. Because the polarity of the stator coils is phased electronically, metal brushes are not needed to mechanically phase the current, thereby reducing friction [11].
A defining parameter of BLDC motors is the Kv value, which is the no-load speed constant of the motor in units of revolutions per minute per volt. Kv describes how fast the motor will spin without external torque when a certain voltage is supplied. For example, a 1000 Kv motor will spin at 1000 rpm when 1 V is applied and 2000 rpm when 2 V are applied. An optimum propulsion design will use a motor with a Kv just large enough to achieve the maximum required revolutions per minute [3]. Figure 4 shows how the BLDC motor weight is affected by Kv as well as the motor’s maximum rated power, outer diameter, and casing length.

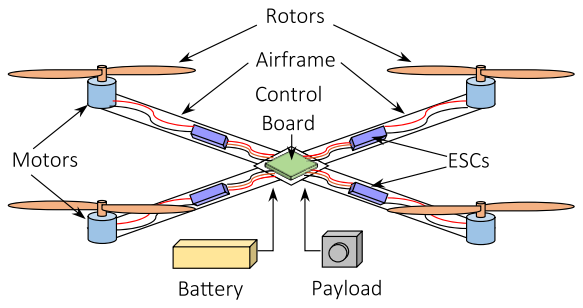
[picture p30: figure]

Fig. 1 General quadrotor schematic.

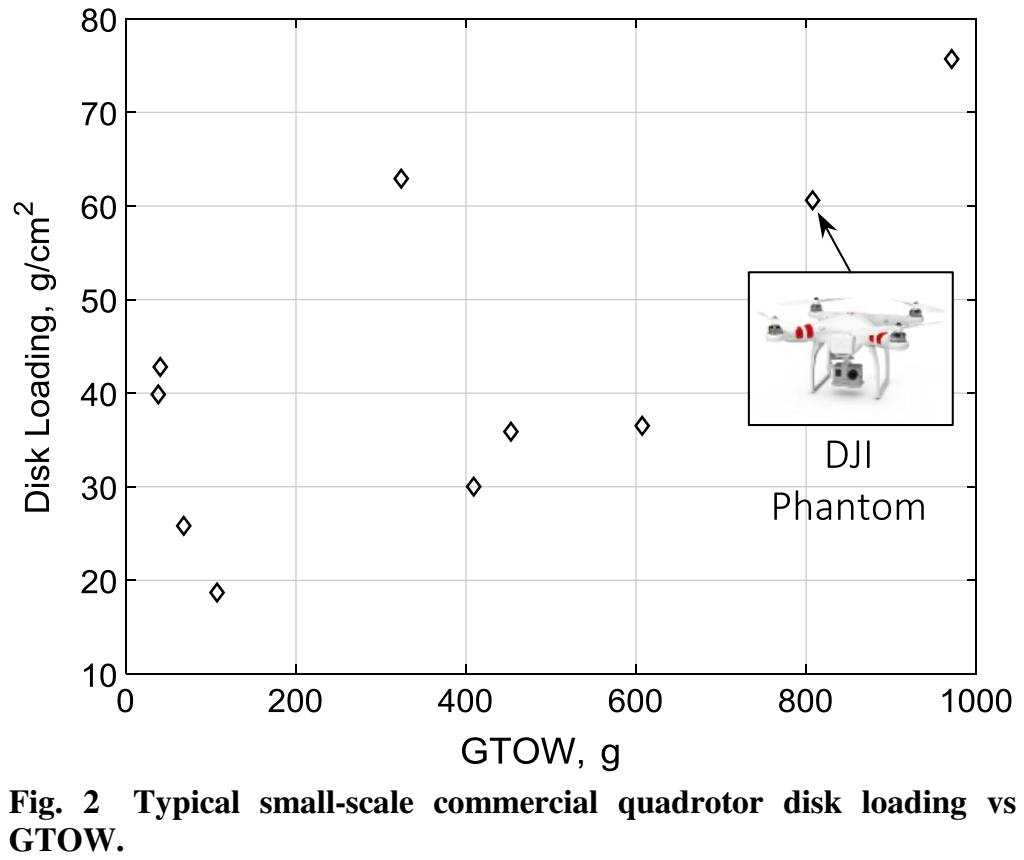
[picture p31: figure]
GTOW.

Fig. 2 Typical small-scale commercial quadrotor disk loading vs

a) b)
Fig. 3 Plots of rotor data (log scale) showing correlation between rotor mass, radius, and blade area.
2 | Article in Advance | / | WINSLOW, HRISHIKESHAVAN, AND CHOPRA
Downloaded by INDIAN INSTITUTE OF TECHNOLOGY on December 10, 2017 | http://arc.aiaa.org | DOI: 10.2514/1.C034483

Data published online§ for these motors have been collected from established motor manufacturers such as Turnigy, ProTronik, NeuMotors, and Portescap.
The second type of electric motor is the brushed motor, which is typically used for quadrotors less than 100 g GTOW. At this scale, previous studies have shown that brushed motors yield higher efficiencies than BLDC counterparts [11]. Also, the simple construction of brushed motors allows them to be lighter. The electronic speed controller, to be described in the next section, also tends to be lighter for brushed motor systems. Figure 5 shows that, for a brushed motor, its mass is largely related to its maximum rated power and output torque, casing diameter, and casing length.
However, the motor diameter and length are not typically design choices for a MAV propulsion system. Therefore, an additional relationship must be used, which relates the diameter and length to required performance variables. Figure 5 indicates that maximum rated motor torque can be used to size the motor length and diameter, and therefore weight.
C. Electronic Speed Controllers
The electronic speed controller is the interface between a motor and the onboard autopilot. The ESC receives a digital signal from the autopilot and then determines how much power to supply to a motor. BLDC and brushed ESCs operate slightly different. Brushed ESCs are simple, in that they only need to switch the voltage to the motor on and off in a duty cycle, effectively changing the average voltage supplied. BLDC ESCs, however, require additional circuits to supply three separate phased signals to the motor and measure back electromotive force [12]. Despite these differences, compiled data for each type of ESC show that both are most directly sized by the maximum electric current rating. The maximum current is the amount of electrical amperage tolerated by the ESCs above which thermal degradation occurs. Figure 6 shows the increase in weight as the maximum allowable current increases for BLDC ESCs.
For brushed ESCs, in the which continuous rated current is also provided, Fig. 6 shows a similar trend between the weight increase with maximum current and with continuous current. The maximum current is the amount of amperage the ESC can sustain for a short time without damage. Continuous current is the amount of amperes the ESC can sustain for an extended period of time.
D. Battery
Lithium–polymer (LiPo) batteries are currently the preferred choice for energy storage on small-scale aerial vehicles.
a) | b) | c) | d)
Fig. 4 Plots of brushless dc motor data (log scale) showing existing correlation between BLDC mass, Kv, maximum rated power, casing diameter, and casing length.
a) | b) | c) | d)
Fig. 5 Plots of brushed motor data (log scale) showing correlation between motor mass, power, maximum continuous torque, casing diameter, and casing length.

Fig. 6 Log-scale plot of ESC (BLDC) data showing correlation between mass and maximum current rating.

§
Data available online at https://hobbyking.com.
Article in Advance | / | WINSLOW, HRISHIKESHAVAN, AND CHOPRA | 3
Downloaded by INDIAN INSTITUTE OF TECHNOLOGY on December 10, 2017 | http://arc.aiaa.org | DOI: 10.2514/1.C034483

This preference is due to their relatively high-energy density as compared to other battery types, allowing greater energy storage for less weight. The key characteristics of a LiPo battery are the rated capacity, voltage level, and number of cells S. The capacity of a battery is given in milliampere hours (abbreviated as mAh). The rated capacity represents the amount of current draw the battery can sustain for 1 h before being completely discharged. The nominal voltage for a LiPo battery is approximately 3.7 V. To increase voltage for larger vehicles, battery cells can be connected in series. Each LiPo cell connected in series will increase the overall voltage of the power supply by 3.7 V. The first plot in Fig. 7 shows how battery weight increases with rated capacity. The second plot in Fig. 7 shows how energy density effectively decreases as more cells are added. This may be due to loss in efficient battery construction as additional cells are added in series. It is therefore pertinent to include this effect within the model.

E. Airframe
The airframe of the quadrotor is the structure on which the payload and all the previously described components are mounted. For most commercially available quadrotors, the airframes are composed of high-density plastic, but some may use carbon fiber. Despite the fact that these airframes can vary significantly based on manufacturer preference.
Figure 8 indicates that, for a range of quadrotors, the airframe weight is largely dependent on rotor diameter and battery mass. These relations appear acceptable because the rotor diameter will dictate minimum airframe dimensions, and the battery comprises a large portion of the GTOW that must be carried by the airframe. The only components labeled in Fig. 1, which are not sized, are the payload and the autopilot. The payload is part of the mission requirements and set by the designer. The autopilot is a digital interface for maintaining quadrotor stability and is not dependent on the gross takeoff weight of the vehicle. A small autopilot used on a 50 g quad can provide equivalent stability and control for a 1000 g quad.

III. Power Requirement Calculation
A key aspect of the sizing methodology is calculating accurate power, torque, and revolution-per-minute levels based on rotor geometry and required thrust. As shown in Figs. 4 and 5, the power and torque requirements are strongly correlated to the motor mass. Motor power will dictate current in the ESC, which will determine its weight according to Figs. 6 and 8. Additionally, operational power coupled with desired flight time will yield a required energy capacity, which will drive the battery sizing as shown in Fig. 7. Battery weight, in turn, is a strong factor in determining airframe weight, as shown in Fig. 8. Therefore, the rotor power, torque, and revolution-per-minute requirements ultimately size the rest of the quadrotor subcomponents.
A. Hover Performance
Determining the thrust and power is even more pertinent at low Reynolds numbers where aerodynamic forces are less understood. In this design tool, the blade element momentum theory (BEMT) in conjunction with computational fluid dynamics (CFD)-generated two-dimensional (2-D) airfoil tables is implemented. This scheme uses the simplicity of the BEMT for rapid calculations and the high accuracy of CFD for low-Reynolds-number sectional aerodynamics. Specifically, the CFD program used was TURNS2-D, which was developed in house, which has been proven to yield reliable lift and drag results at low Reynolds numbers [13,14]. Figure 9 shows the dimensional thrust, power, and torque quantities generated by the BEMT-CFD validated against experimental measurements for a rotor on a commercially available Syma X5 quadrotor. This rotor is
a) b)
Fig. 7 Plot of LiPo battery data showing existing correlation of mass with rated capacity and energy density with the number of cells in the series.
a) b)
Fig. 8 Log-scale plot of airframe data showing correlation of mass with rotor diameter and battery mass.
4 | Article in Advance | / | WINSLOW, HRISHIKESHAVAN, AND CHOPRA
Downloaded by INDIAN INSTITUTE OF TECHNOLOGY on December 10, 2017 | http://arc.aiaa.org | DOI: 10.2514/1.C034483

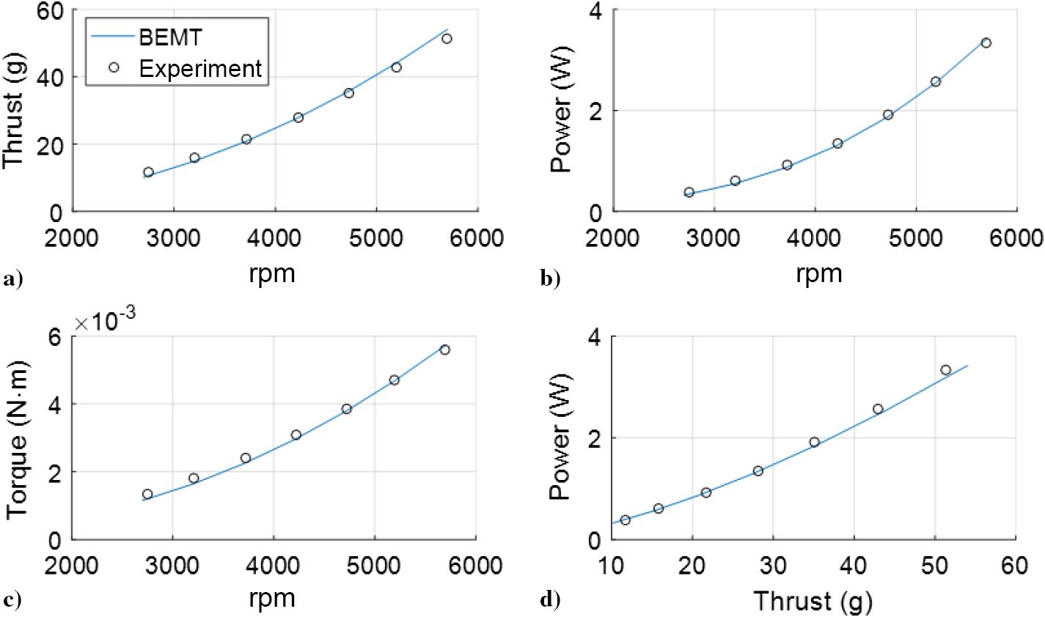
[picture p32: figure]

characterized by a 135-mm-diam 0.58-linear-chord taper ratio, with a 13 deg collective (at 75%R), a −5 deg twist rate, and a NACA6504 airfoil section, which is shown in Fig. 11b. Figure 10 shows the close prediction of the BEMT-CFD-generated hover efficiency (figure of merit) with experimental measurements for an optimized microrotor designed in a previous study [11]. This rotor is characterized by an 82-mm-diam 0.5-chord-taper ratio (root chord/tip chord) −11.4 deg twist rate, and a cambered plate airfoil section with a 2.2% thickness and 6.1% camber. Both the nondimensional and dimensional results indicate that the BEMT can reliably predict low–Reynolds-number rotor performance when coupled with sectional CFD tables.
Due to rotor stall effects at high CT values, there can be some discrepancy observed in BEMT correlation. This can be improved in the future through better stall prediction models for low-Reynolds-number airfoils.
B. Forward-Flight Performance
To quickly obtain power, torque, and revolution-per-minute requirements for forward (edgewise) flight, a momentum theory analysis [15] was used. In this theory, the power required for steady level forward flight can be separated into three components: induced

Fig. 9 Comparison of BEMT with CFD airfoil lookup tables to experimentally tested Syma X5 rotor (tip Reynolds number of ∼50;000 at 5000 rpm).

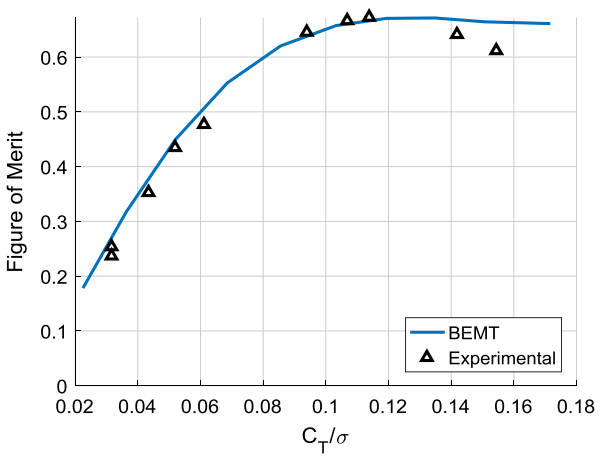
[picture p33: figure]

Fig. 10 Figure of merit vs CT∕σ validation for a microrotor with an 82-mm-diam 0.5-chord-taper ratio, with a −11.4 deg twist rate and cambered plate airfoil.

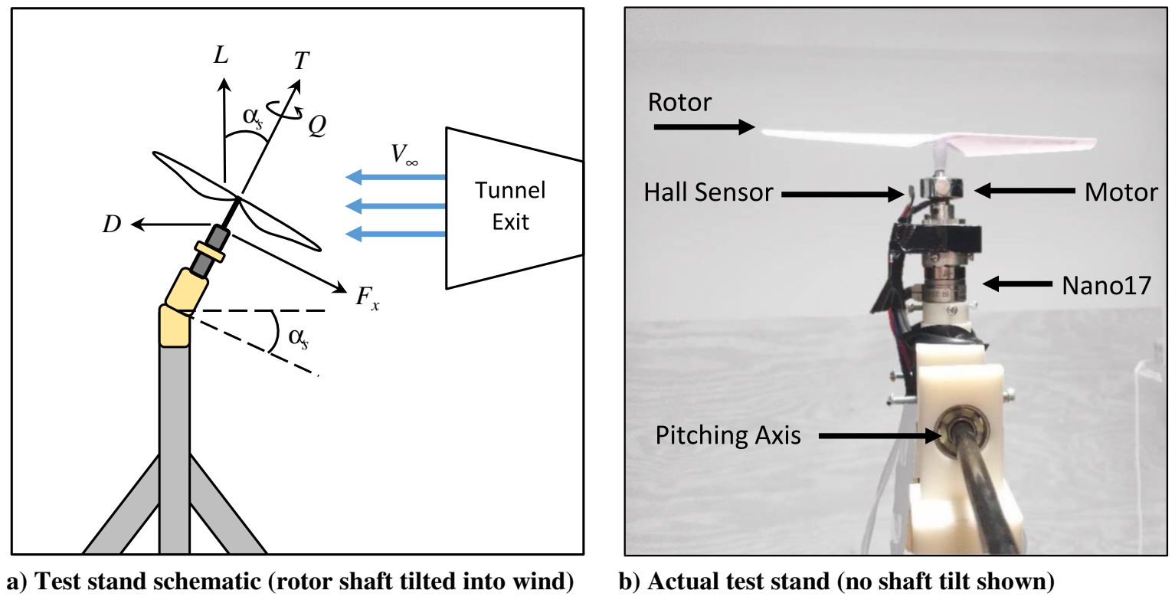
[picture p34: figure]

a) Test stand schematic (rotor shaft tilted into wind) b) Actual test stand (no shaft tilt shown) Fig. 11 Experimental setup used for wind-tunnel testing.
Article in Advance | / | WINSLOW, HRISHIKESHAVAN, AND CHOPRA | 5
Downloaded by INDIAN INSTITUTE OF TECHNOLOGY on December 10, 2017 | http://arc.aiaa.org | DOI: 10.2514/1.C034483

Pi, profile Po, and parasitic Pp power [15]. However, the equations for these terms contain empirical factors such as the induced power factor κ, the profile power factor K, and the equivalent flat-plate area f for parasitic drag estimation. Due to the difference in Reynolds number, rotor design, rotor configuration, and airframe geometry between large-scale helicopters and small-scale quadrotors, typical values assumed for these factors are not applicable for MAVs. Currently, experimental data for rotary-wing MAV performance in forward flight are lacking, making it difficult to obtain realistic values for the power factors. From a recent study at the NASA Ames Research Center, the test data from the wind-tunnel setup provide force and moment measurements for five commercial multicopters at various flow speeds and body-pitch angles [16].
Although the results of this study are useful for the vehicle lift and drag data, these do not provide much insight into the induced and profile power contributions from a typical MAV-scale rotor at multiple flight speeds. Furthermore, the vehicles tested were mostly larger (GTOW > 1.27 kg) than the vehicles of interest in the present research.
To obtain a set of validation data for rotor power in forward flight, wind-tunnel tests were conducted on a typical MAV rotor that is used on the Syma X5 quadrotor. A depiction of the experimental setup used for wind-tunnel testing is shown in Fig. 11. Force and moment measurements were taken with a six-axis load cell (Nano17). The revolutions per minute were measured by fixing magnets to the motor and recording the frequency at which they passed a Hall effect sensor. The shaft tilt αs (or body pitch for the fuselage) was precisely changed with a digital servo coupled with a pitching axis below the Nano17. In addition to the isolated rotor configuration shown in Fig. 11, the Syma X5 airframe without rotors was placed on the test stand to acquire an equivalent flat-plate area drag measurement. Wind-tunnel speeds examined were V∞ 2, 4, and 6m∕s. For each wind speed, the shaft tilts examined were αs 0, 2, 5, 10, 15, 20, 30, and 40 deg. The nominal rotor speed for hover was determined to be 4200 rpm. Therefore, speeds of 3200, 3500, 4200, 4700, and 5200 rpm were examined at each shaft tilt angle. Additionally, measurements were repeated at each wind speed and shaft tilt with the rotor removed to obtain aerodynamic tares to correct the data in postprocessing. The trim condition for steady level forward flight was met when the thrust from the rotor at required shaft tilt was able to balance both the lift with 1/4 the GTOW (for a quadrotor) and the propulsive force with the drag at a given airspeed. The required thrust T, revolutions per minute, torque Q, and shaft tilt αs were interpolated from the wind-tunnel data where the trim condition was met for each wind speed. By multiplying the torque and revolutions per minute, the required mechanical power from the rotor could be determined and used for validation for the calculated power. The validation for the isolated rotor power is shown in Fig. 12. These results show that the momentum theory analysis can be valid by assuming larger power factors than would be used for full-scale helicopters. Whereas the induced power factor would be typically be assumed as κ 1.15, the present analysis shows that κ 1.5 is more realistic for a MAV-scale rotor. It should also be noted that the profile power increases with flight speed much more than usual. This is likely due to the increased effect of viscous drag forces in the low-Reynolds-number regime (20,000–40,000 tip Reynolds numbers) at which these rotors operate. Using the momentum theory analysis, power estimates can be obtained at different desired air speeds. By multiplying the rotor power by the number of rotors and accounting for the drag of the fuselage at its required body pitch angle, a power estimate for cruise can be calculated. Given that the power required varies as a function of flight speed, mission segments for hover or forward flight will drain stored energy at different rates. Additionally, the primary mission requirement (such as long endurance or high speed) will determine the maximum power required, which will drive different choices of quadrotor subcomponents: particularly the motors.

IV. Component Weight Regression Analysis
A parameterization technique similar to the previous sizing methods [5] was used to develop empirical equations for sizing quadrotor components. In this method, the dependent variable data (component weight) and the independent parameters (e.g., rotor radius, power requirements, and energy capacity) are first transformed into the log10 domain. Then, a multivariable linear regression algorithm is used to solve for the unknown coefficients, which yield the best fit for the given data. The resulting equation is then transformed back to the original domain and the coefficients become the exponents of the independent variables.
This section provides examples of the predicted component weights generated by the regression analysis. Sizing equations for each quadrotor component are provided. Though validation for each sizing equation has been attempted, only two examples for the rotor and battery are shown. The subsequent figures represent how the predicted weight compares to the actual weight of each component. Two measures of accuracy for the predicted weight are provided in each figure: R2 value and linear-fit slope.
A. Rotors
Using the weight trends observed in the rotor data, a regression analysis was performed on the rotor weight with the radius, solidity, and number of blades as the dependent variables. Figure 13 shows the agreement between the predicted rotor weight and the measured weight: particularly for lighter rotors.
The resulting equation used to generate predicted rotor mass mR in

grams is as follows:

Fig. 13 Validation of regression-derived rotor weight with measured


Fig. 12 Calculated isolated rotor power compared to wind-tunnel data. | rotor weight.
6 | Article in Advance | / | WINSLOW, HRISHIKESHAVAN, AND CHOPRA
Downloaded by INDIAN INSTITUTE OF TECHNOLOGY on December 10, 2017 | http://arc.aiaa.org | DOI: 10.2514/1.C034483

weight.; Actual Weight (g); Predicted Weight (g); Slope: 0.92651; measured weight.; Article in Advance; WINSLOW, HRISHIKESHAVAN, AND CHOPRA

where R is the rotor radius in centimeters, σ is the solidity, and Nb is the number of blades.

B. Battery
Using the battery weight trends with the energy capacity and number of cells, a predicted weight equation was generated. Figure 14 shows the agreement between the predicted battery weight and the measured battery weight.
The regression equation used to generate predicted battery mass mB in grams is as follows:
mB 0.0418C⁰.9327S¹.0725 | (2)

where C is the battery capacity in milliamperes per hour, and S is the number of cells in the series.

C. Brushless Motors
The regression equation to generate the predicted BLDC motor mass mBL in grams is as follows:

mBL 0.0109K0.5122

v | P−0.1902log lBL².5582log dBL¹².8502 | (3)

where Kv is the motor speed constant in revolutions per minute per volt, P is the maximum rated output power in watts, lBL is the motor casing length in millimeters, and dBL is the outer motor diameter in millimeters.
The equation to generate the predicted BLDC motor casing length lBL in millimeters is as follows:
lBL 4.8910I0.1751P0.2476 | (4)

where I is the maximum required current for the motor in amperes, and P is the maximum rated output power in watts.
The equation to generate the predicted BLDC motor diameter dBL in millimeters is as follows:

dBL 41.45K−0.1919
v | P0.1935 | (5)

where Kv is the motor speed constant in evolutions per minute per volt, and P is the maximum rated output power in watts.

D. Brushed DC Motors
The equation to generate the predicted brushed Dc motor mass mDC in grams is as follows:

mDC 10−84P−0.2979Q−20.5615

max log lDC⁷⁴⁶log dDC⁻²¹² (6)


where P is the maximum rated output power in watts, Qmax is the maximum output torque in millinewtons per meter, lDC is the motor casing length in millimeters, and dDC is the outer motor diameter in millimeters. Figure 15 shows a comparison between the actual and the predicted weights from the regression analysis.
The equation to generate the predicted brushed dc motor casing length lDC in millimeters is as follows:

lDC 20.83Q⁰.1924
max | (7)

and the equation to generate predicted the brushed dc motor casing diameter dDC in millimeters is as follows:

dDC 11.13Q⁰.2895
max | (8)

where Qmax is the maximum output torque in millinewtons per meter.

E. ESC for Brushless Motors
The equation to generate the predicted ESC mass for BLDC motors mEBL in grams is as follows:

mEBL 0.8013I0.9727
max | (9)

where Imax is the maximum sustainable current through the ESC in amperes.

F. ESC for Brushed DC Motors
The equation to generate the predicted ESC mass for brushed motors mEDC in grams is as follows:

mEDC 0.977I0.8483
max | (10)

where Imax is the maximum burst current through the ESC in amperes.
A second equation to generate the predicted ESC mass for brushed motors mEDC in grams is as follows:

mEDC 1.9I0.7415
cont | (11)

where Icont is the maximum continuous operation current through the ESC in amperes.

G. Airframe
The equation to generate the predicted airframe mass mA in grams is as follows:

mA 1.3119R1.2767m0.4587
B | (12)

Fig. 14 Validation of regression-derived battery weight with measured Fig. 15 Validation of regression-derived brushed dc motor weight with

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

Inputs; Flight Time; No. of Cells; GTOWi; Payload; RPM; Motor; Type; mDC; mBL; P, RPM; mESC; Imax; BEMT; GTOWi+1 < GTOWi; Yes; Exit; Increase; Article in Advance; WINSLOW, HRISHIKESHAVAN, AND CHOPRA

where R is the rotor radius in centimeters, and mB is the mass of the battery in grams.

V. Complete Sizing Algorithm
A. Description
The sizing equations and BEMT functions have been integrated into a complete parametric sizing tool. A high-level schematic depicting the sizing algorithm and component interaction is shown in Fig. 16. It is noted that the following section discusses the case for hover but can be extended to forward speed as well. The required inputs are the desired flight time, the number of battery cells S, the rotor radius R, the solidity σ, the number of blades Nb, the payload weight, and an initial guess for the GTOW. The initial guess for the GTOW is taken as a certain multiplier of the desired payload weight (three in this case). The rotor mass can be determined directly from theR, σ, and Nb inputs, as shown in Eq. (1). A BEMT subroutine uses the input parameters to generate rotor thrust, power, torque, and revolutions per minute. These performance parameters dictate the motor requirements and weight. The GTOW also dictates the type of motor to be used: typically, BLDC motors for GTOW > 100 g and brushed DC motors for GTOW < 100 g. The power is also multiplied by the flight time and divided by the battery voltage to determine the required battery capacity (Coulombs in milliamperes per hour), which is a strong driver of the battery weight, as seen in Eq. (2). The battery weight then factors into the airframe weight with the rotor radius via Eq. (12). When all subcomponent weights have been calculated, they are summed into a new GTOW. The code checks that the new GTOWis less than the previous GTOW. If false, the GTOWis incrementally increased and the sizing loop begins again. If true, then the calculated propulsion system is sufficient to carry out the desired hover mission and the algorithm stops. Typically, the initial guess for the GTOW is chosen conservatively low such that it approaches the final solution from below. The update is done in a fixed-point manner, and it is easier to converge from a lower value because the sizing equations are generally monotonically increasing.
B. Validation
To prove the utility of the proposed quadrotor MAV sizing code, a weight measurement breakdown was conducted on a variety of existing quadrotors. The major weight groups (rotors, motors, ESCs, battery, and airframe) were isolated and weighed individually, in addition to the GTOW of each vehicle. A sample of the calculated sizing results compared to the measured values for each weight group is provided in Table 1. Both brushed- and brushless-motor-based vehicles are presented. The reported flight time and basic rotor information (R, σ, Nb, and assumed airfoil) for each vehicle were the primary sizing inputs. The payload weight contained items such as the autopilot board, light-emitting diodes, and cameras; and they were not calculated by the sizing algorithm. As seen in Table 1, the majority of the percent error between measured and calculated weights falls within 10%. Furthermore, the GTOW of each vehicle is predicted well, with a percent error within 4%.

Fig. 16 Sizing algorithm and interactions.

Table 1 Comparison of various quadrotor weight groups to sizing code outputs

Quadrotor/motor type
| | Holy Stone DFD/brushed | UDIRC U816A/brushed | Syma X5/brushed | Syma X8G/brushless | DJI Phantom 1/brushless
Rotor | Measured, g | 1.44 | 1.48 | 7.72 | 34.3 | 28.4
| Calculated, g | 1.35 | 1.35 | 9.02 | 28.6 | 23.4
| Error, % | −6.47 | −9 | 16.9 | −16.5 | −17.8
Motor | Measured, g | 13.9 | 13.6 | 15 | 122 | 203
| Calculated, g | 14.7 | 15.3 | 14.4 | 126 | 198
| Error, % | 5.63 | 12.7 | −3.91 | 4.01 | −2.73
ESC | Measured, g | 0.294 | 0.383 | 0.493 | 21.2 | 40.4
| Calculated, g | 0.304 | 0.327 | 0.5 | 24 | 27
| Error, % | 3.42 | −14.6 | 1.36 | 13.1 | −33.3
Battery | Measured, g | 8.44 | 8.3 | 14.7 | 110 | 170
| Calculated, g | 7.37 | 8.08 | 15.8 | 84.8 | 186
| Error, % | −12.7 | −2.69 | 7.27 | −22.6 | 9.46
Airframe | Measured, g | 11.3 | 13.1 | 51.4 | 198 | 268
| Calculated, g | 11.9 | 12.4 | 53.3 | 227 | 283
| Error, % | 6.03 | −4.79 | 3.58 | 14.9 | 5.58
GTOW | Measured, g | 37.9 | 40.6 | 108 | 608 | 808
| Calculated, g | 38.3 | 40.9 | 111 | 615 | 808
| Error, % | 0.964 | 0.784 | 3.36 | 1.09 | −0.011
Downloaded by INDIAN INSTITUTE OF TECHNOLOGY on December 10, 2017 | http://arc.aiaa.org | DOI: 10.2514/1.C034483

VI. Conclusions
A design tool for low-Reynolds-number (10,000–100,000 Reynolds numbers)-scale quadrotor aircraft is proposed. Provided with general mission requirements (endurance, speed, and payload) and basic rotor parameters, the design tool outputs require subcomponent weights and total vehicle size and weight. In hover scenarios, the blade element momentum theory in conjunction with computational fluid dynamics-generated low–Reynolds-number airfoil tables is a fast and reliable method to calculate the required torque and power. Forward-flight performance data for a low-Reynolds-number rotor is collected, which indicates relatively high-power requirements as the forward-flight speed increases. These data are required to build more accurate semiempirical models to size quadrotors for different flight speeds, depending on mission requirements. However, due to the lack of low-Reynolds-number forward-flight rotor data, more experiments should be conducted to further validate the model. Data on each quadrotor component are compiled and analyzed to determine key weight-driving factors. Sizing equations are derived using a log–log multivariable linear regression technique. The sizing equations are validated against the survey of available data for each component. The sizing model is also compared to existing quadrotor micro air vehicles in terms of individual component weights and gross takeoff weight (GTOW). Individual weight groups can be predicted generally within a 10% error, and the GTOW of each vehicle is predicted within a 4% error.

Acknowledgments
The authors would like to extend special thanks to the members of Vertical lift research center of excellence, Alex Moodie, and the other members of the NASA Langley Research Center U.S. Army Concept Design and Assessment for their support of this project. The authors would also like to thank Ehiremen Ebiwele for assistance with wind-tunnel tests.

References

[1] Bouabdallah, S., and Siegwart, R., “Design and Control of a Miniature Quadrotor,” Advances in Unmanned Aerial Vehicles, Springer, Dordrecht, The Netherlands, 2007, pp. 171–210.
[2] Ampatis, C., and Papadopoulos, E., “Parametric Design and Optimization of Multi-Rotor Aerial Vehicles,” Applications of Mathematics and Informatics in Science and Engineering, Springer International, New York, 2014, pp. 1–25.
[3] Bershadsky, D., Haviland, S., and Johnson, E. N., “Electric Multirotor Propulsion System Sizing for Performance Prediction and Design Optimization,” AIAA SciTech 2016, AIAA Paper 2016-0581,

2016.
doi:10 (http://dx.doi.org/10.2514/6.2016-0581).2514/6 (http://dx.doi.org/10.2514/6.2016-0581).2016-0581 (http://dx.doi.org/10.2514/6.2016-0581)
[4] eCalc: xcopterCalc—Multicopter Calculator (online database), http://www.ecalc.ch/xcoptercalc.php [retrieved Nov. 2016].
[5] McMasters, J. H., and Cummings, R. M., “Rethinking the Airplane Design Process—An Early 21st Century Perspective,” 42nd Aerospace Sciences Meeting, AIAA Paper 2004-0693, Jan. 2004. doi:10 (http://dx.doi.org/10.2514/6.2004-693).2514/6 (http://dx.doi.org/10.2514/6.2004-693).2004-693 (http://dx.doi.org/10.2514/6.2004-693)
[6] Johnson, W., “NDARC—NASA Design and Analysis of Rotorcraft. Theoretical Basis and Architecture,” American Helicopter Society Aeromechanics Specialist’s Conference Proceedings, American Helicopter Soc., San Francisco, CA, Jan. 2010.
[7] Sinsay, J. D., and Nunez, G. F., “Toward Right-Fidelity Rotorcraft Conceptual Design,” 51st AIAA/ASME/ASCE/AHS/ASC Structures, Structural Dynamics, and Materials Conference, AIAA Paper 2010-2756, April 2010.
doi:10 (http://dx.doi.org/10.2514/6.2010-2756).2514/6 (http://dx.doi.org/10.2514/6.2010-2756).2010-2756 (http://dx.doi.org/10.2514/6.2010-2756)
[8] Johnson, W., “Propulsion System Models for Rotorcraft Conceptual Design,” American Helicopter Society 5th Decennial Aeromechanics Specialists’ Conference, American Helicopter Soc., San Francisco, CA.
[9] Datta, A., and Johnson, W., “Powerplant Design and Performance Analysis of a Manned All-Electric Helicopter,” Journal of Propulsion and Power, Vol. 30, No. 2, 2014, pp. 490–505.
doi:10 (http://dx.doi.org/10.2514/1.B34843).2514/1 (http://dx.doi.org/10.2514/1.B34843).B34843 (http://dx.doi.org/10.2514/1.B34843)
[10] Sinsay, J., Alonso, J., Kontinos, D., Melton, J., and Grabbe, S., “Air Vehicle Design and Technology Considerations for an Electric VTOL Metro-Regional Public Transportation System,” 12th AIAA Aviation Technology, Integration, and Operations Conference, AIAA Paper 2012-5404, Sept. 2012.
doi:10 (http://dx.doi.org/10.2514/6.2012-5404).2514/6 (http://dx.doi.org/10.2514/6.2012-5404).2012-5404 (http://dx.doi.org/10.2514/6.2012-5404)
[11] Winslow, J., Benedict, M., Hrishikehavan, V., and Chopra, I, “Design, Development, and Flight Testing of a High Endurance Micro Quadrotor Helicopter,” American Helicopter Society International Specialists’ Meeting on Unmanned Rotorcraft Systems, Chandler, AZ, 2015.
[12] Harrington, A., and Kroninger, C., “Characterization of Small DC Brushed and Brushless Motors,” U.S. Army Research Lab. Rept. ARL-TR-6389, March 2013.
[13] Yang, K., “Aerodynamic Analysis of an MAV-Scale Cycloidal Rotor System Using a Structured Overset RANS Solver,” M.S. Thesis, Dept. of Aerospace Engineering, Univ. of Maryland, College Park, MD, 2010.
[14] Shivaji, M., “Correlation-Based Transition Modeling for External Aerodynamic Flows,” Ph.D. Dissertation, Dept. of Aerospace Engineering, Univ. of Maryland, College Park, MD, 2014.
[15] Leishman, J.G., Principles of Helicopter Aerodynamics, Cambridge Univ. Press, New York, 2006, pp. 37–52.
[16] Russell, C., Jung, J., Willink, G., and Glasner, B., “Wind Tunnel and Hover Performance Test Results for Multicopter UAS Vehicles,” American Helicopter Society 72nd Annual Forum, American Helicopter Soc., West Palm Beach, FL, May 2016.
Article in Advance | / | WINSLOW, HRISHIKESHAVAN, AND CHOPRA | 9
Downloaded by INDIAN INSTITUTE OF TECHNOLOGY on December 10, 2017 | http://arc.aiaa.org | DOI: 10.2514/1.C034483

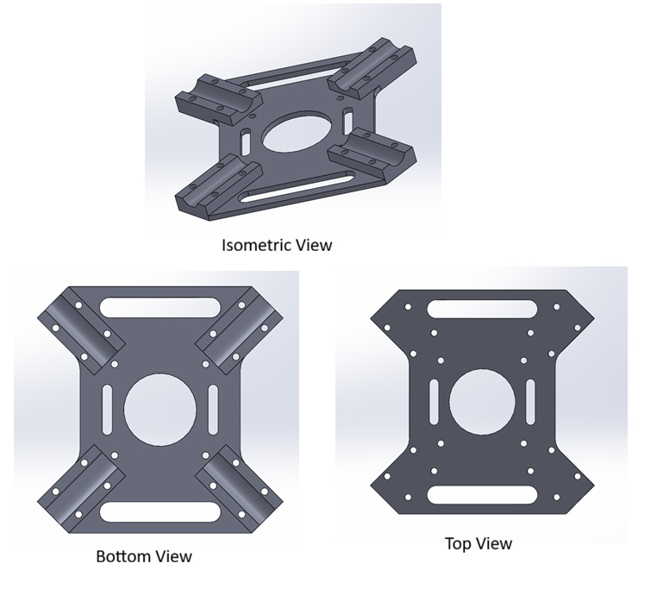
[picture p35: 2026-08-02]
cad/render_images/Top Plate.jpg

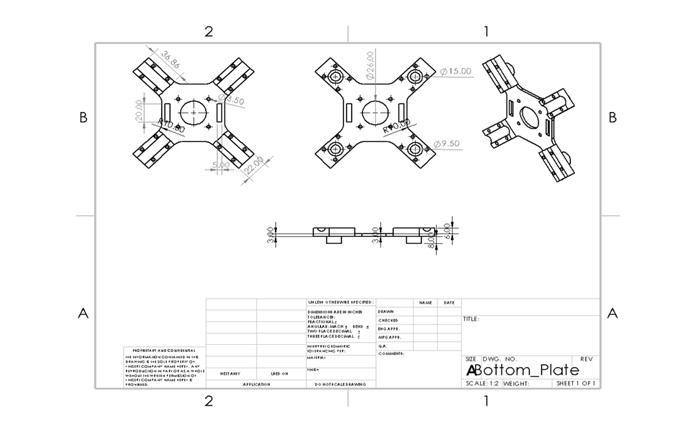
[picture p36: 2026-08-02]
cad/render_images/bottom plate with dim.jpg

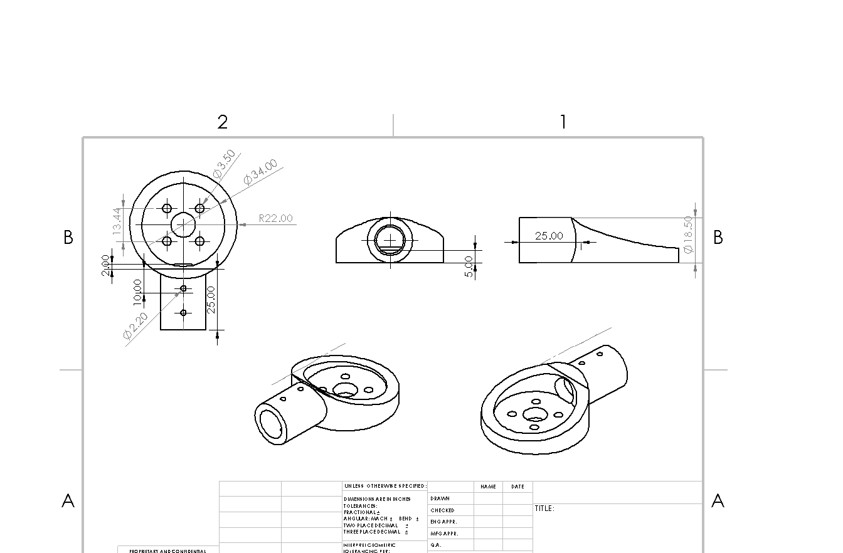
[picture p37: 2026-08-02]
cad/render_images/motor mount with dim.jpg

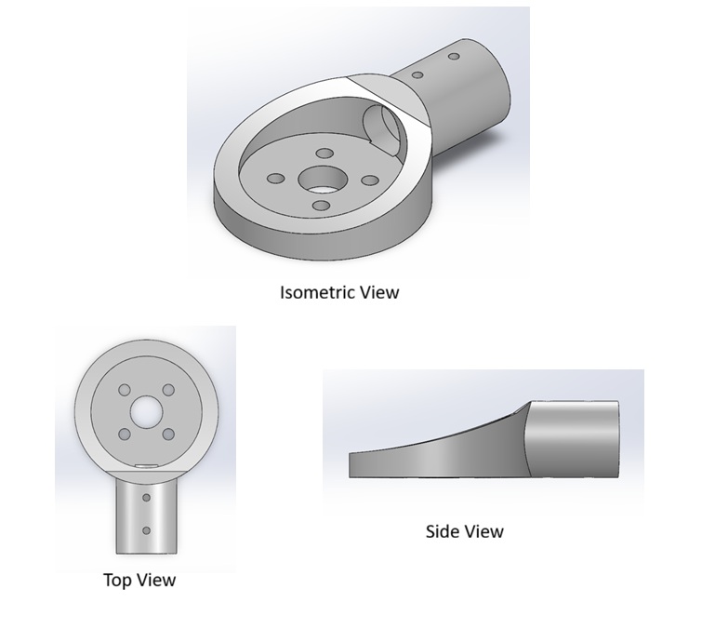
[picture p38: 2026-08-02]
cad/render_images/motor mount.jpg

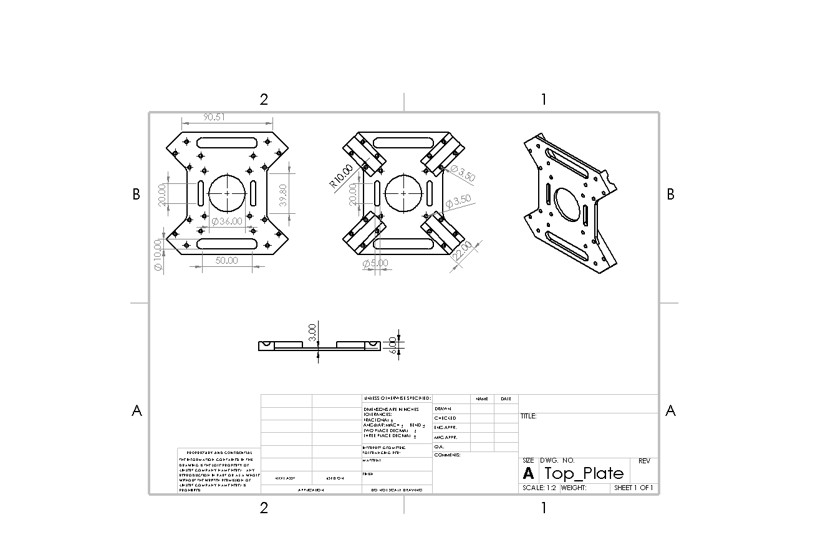
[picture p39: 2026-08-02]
cad/render_images/top plate with dim.jpg

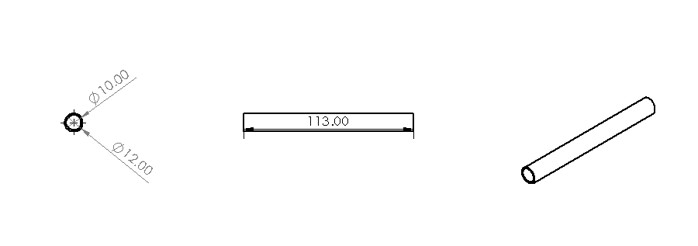
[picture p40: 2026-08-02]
cad/render_images/arms with dim.jpg

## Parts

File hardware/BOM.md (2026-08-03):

# Bill of Materials

As-built configuration (Config 5). Masses are measured unless marked *spec*.

## Propulsion

| Item | Part | Qty | Unit mass | Total | Notes |
|---|---|---|---|---|---|
| Motor | Emax ECOII-2807, 1300 Kv | 4 | 54 g | 216 g | Substitute for BrotherHobby Avenger 2806.5 (unavailable) |
| Propeller | Gemfan Flash 7042, 7.0 × 4.2, PC | 4 | 6 g | 24 g | Bi-blade |
| ESC | Holybro Tekko32 F4 4-in-1 | 1 | 13.8 g | 13.8 g | 50 A continuous / 60 A burst |

## Power

| Item | Part | Qty | Unit mass | Total | Notes |
|---|---|---|---|---|---|
| Battery | Molicel INR21700-P45B 4S1P | 1 | 313 g | 313 g | 14.4 V nominal, 4500 mAh, 64.8 Wh |

**Pack current limit:** 45 A continuous. Hover draw ≈ 16 A. Note that full-throttle
demand (4 × 47.9 A ≈ 191 A) exceeds pack capability — usable thrust ceiling is
pack-limited to roughly 900 g/motor, still ~3× hover.

## Avionics

| Item | Part | Qty | Unit mass | Total |
|---|---|---|---|---|
| Flight controller | Pixhawk (with case) | 1 | 38 g *est.* | 38 g |
| Receiver | 2.4 GHz RC receiver | 1 | 10 g *est.* | 10 g |
| Power module | Voltage/current sense module | 1 | 22 g *est.* | 22 g |
| Wiring harness | Silicone wire, XT60, connectors | 1 | 40 g *est.* | 40 g |
| Mounting hardware | Damping pads, straps, standoffs, zip ties, etc | — | 40 g *est.* | 40 g |
| **Subtotal** | | | | **150 g** |

## Structure

| Item | Spec | Qty | Total mass |
|---|---|---|---|
| Top plate | 3 mm, X profile | 1 | |
| Bottom plate | 3 mm, X profile | 1 | |
| Arms | 12 mm OD aluminium tube, 113 mm | 4 | |
| Motor mounts | 36 mm ID / 44 mm OD, gusseted | 4 | |
| Landing gear | 9 mm aluminium rod | 4 | |
| M3 × 25 mm bolts + nuts | arm clamping | 16 | |
| M3 × 6 mm bolts | Pixhawk mounting | 4 | |
| M3 × 3 mm bolts | motors + ESC | 20 | |
| **Frame subtotal** | | | **220 g** |

## Mass summary

| Group | Mass |
|---|---|
| Propulsion | 253.8 g |
| Power | 313.0 g |
| Avionics & wiring | 150.0 g |
| Structure | 220.0 g |
| Payload | 300.0 g |
| **All-up weight** | **1236.8 g** |

## Bench test data

Emax ECOII-2807-1300Kv with Gemfan 7042.

> **Voltage caveat:** manufacturer data below is quoted at 25.2 V (6S).
> The vehicle runs 4S (14.4 V nominal). Re-measure at 4S before using these
> figures for endurance prediction — the operating point differs.

| Throttle | Current (A) | Thrust (g) | Power (W) | Efficiency (g/W) | RPM |
|---|---|---|---|---|---|
| Hover | 2.2 | 300 | 55.4 | 5.41 | 8 440 |
| Medium | 4.0 | 500 | 100.8 | 4.96 | 10 550 |
| High | 9.3 | 900 | 234.4 | 3.84 | 13 960 |
| Maximum | 47.9 | 2190 | 1207.1 | 1.81 | — |

## Derived performance

| Quantity | Value |
|---|---|
| Thrust per motor at hover | 309 g |
| Total hover power | ≈ 228 W |
| Usable battery energy (85% DoD) | 55.1 Wh |
| **Estimated hover endurance** | **≈ 14.5 min** |
| Disc loading | ≈ 122 N/m² |
| Thrust-to-weight (pack-limited) | ≈ 2.9 |

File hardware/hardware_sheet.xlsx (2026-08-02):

Component | Name | Specification | Link
Propeller | 4PCS Gemfan Flash 7042 (7x4.2) 7 Inches 2 Blade Propeller | No of Unis: 4 2x Gemfan Flash 7042 Durable 2 Blade CW 2x Gemfan Flash 7042 Durable 2 Blade CCW Item name: flash 7042 2-blade propeller Size: 7042, 7.0×4.2 Material: PC Weight: 5.48g Mounting hole: 5mm Paddle size: 14mm Hub thickness: 7.5mm Suitable for 2407-2408 motors | quadkart prop link in stock (https://www.quadkart.in/gemfan-flash-7042-durable-2-blade-propeller/) | vegadrones.in prop link in stock (https://vegadrones.in/product/gemfan-7042-flash/) | amazon.in prop link in stock (https://www.amazon.in/Gemfan-Inches-Propeller-Racing-Quadcopter/dp/B07PMQSWFR)
Motor | Emax ECOII-2807-1300KV Brushless Motor | No of Unis: 4 Motor KV (RPM/V): 1300 Motor Type: Brushless Motor Model Name: Emax ECOII-2807-1300KV Bearing: 4mm Idle Current(A): 1.3A No. of Cells: 3-6 cell Compatible Prop (inch): 06-07" Max. Power (W): 1310W Motor Weight (g): 54g | rubo.in for motor in stock (https://robu.in/product/emax-ecoii-2807-1300kv-brushless-motor)
ESC | Holybro Tekko32 F4 4in1 50A ESC | No of Unis: 1 Continuous Current 50A x4 Burst Current 60A x4 Supports 4-6S battery Weight (g): 13.8g | a) rubo.in link 4 in 1 esc in stock (https://robu.in/product/holybro-tekko32-f4-4in1-50a-esc/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)
Battery | Pro-Range A Grade INR 21700-P45B 14.8V 4500mAh 10C 4S1P 40A/45A Discharge Li-ion Drone Battery Pack with Twin Connector | Weight: 313g Voltage: 14.8V Nominal Capacity (mAh): 4500 Discharge Current: 10C | robu.in link for battery in stock (https://robu.in/product/pro-range-inr-21700-p45b-14-8v-4500mah-4s1p-40a-45a-discharge-li-ion-drone-battery-pack/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)

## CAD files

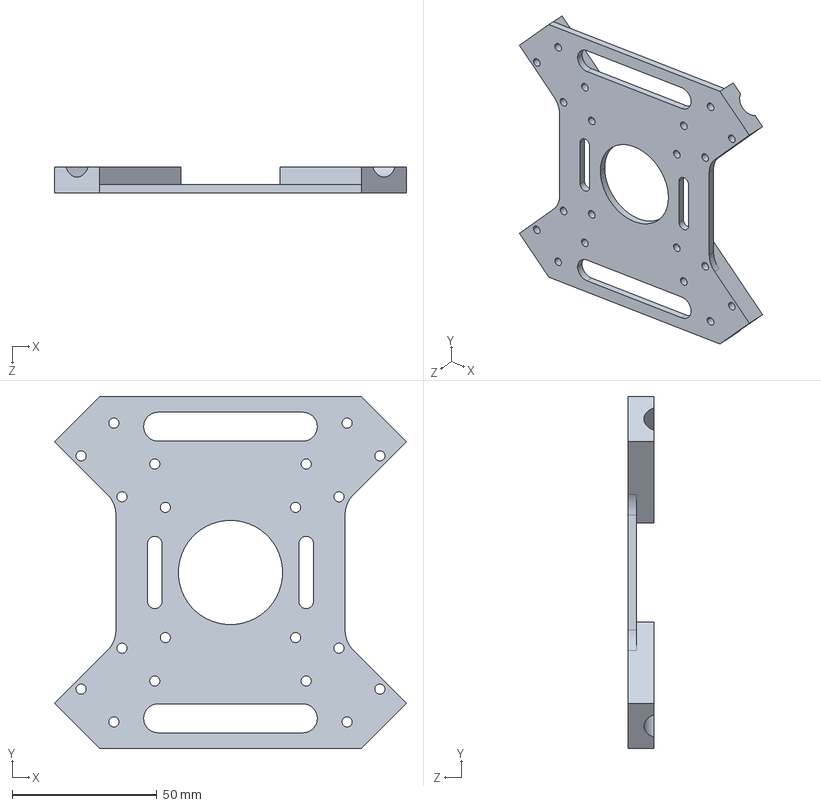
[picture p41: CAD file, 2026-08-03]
cad/cad_files/Top_Plate.STEP
121.6 x 121.6 x 9.00 mm

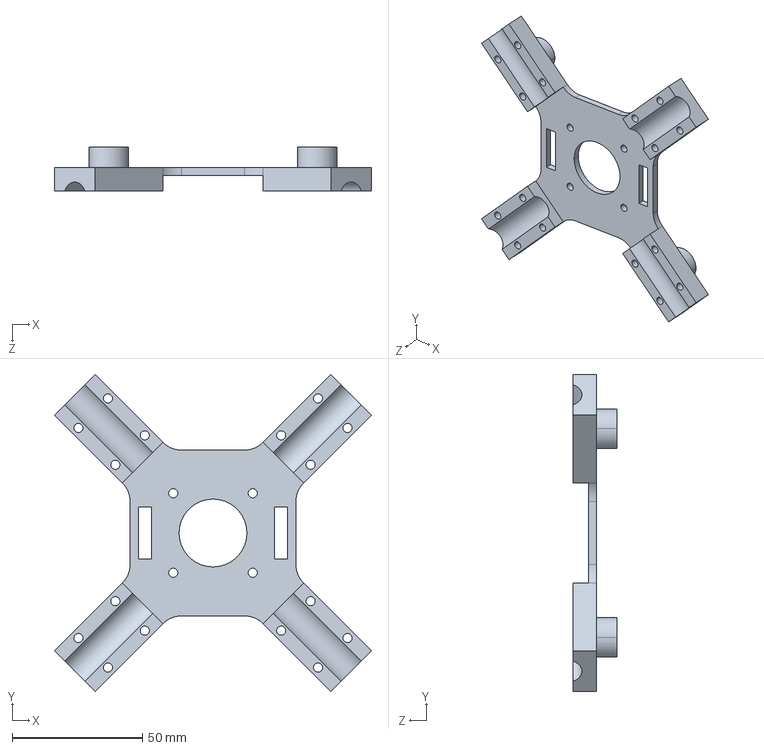
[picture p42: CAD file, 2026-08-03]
cad/cad_files/Bottom_Plate.STEP
121.6 x 121.6 x 17.0 mm

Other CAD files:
cad/cad_files/Bottom_Plate.SLDDRW
cad/cad_files/Bottom_Plate.SLDPRT
cad/cad_files/Part_Arm.SLDDRW
cad/cad_files/Part_Motor_Mount_final.SLDDRW
cad/cad_files/Top_Plate.SLDDRW
cad/cad_files/Top_Plate.SLDPRT

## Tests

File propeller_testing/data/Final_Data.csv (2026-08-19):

RPM | Time (s) | ESC signal (Âµs) | Servo 1 (Âµs) | Servo 2 (Âµs) | Servo 3 (Âµs) | AccX (g) | AccY (g) | AccZ (g) | Torque (NÂ·m) | Thrust (gf) | Voltage (V) | Current (A) | Motor Electrical Speed (RPM) | Motor Optical Speed (RPM) | Electrical Power (W) | Mechanical Power (W) | Motor Efficiency (%) | Propeller Mech. Efficiency (gf/W) | Overall Efficiency (gf/W) | Vibration (g) | App message | Unnamed: 21
0 | 0 | 0 |  |  |  | 0 | 0 | 0 | 0 | 0 | 0 | 0 | 0 | 0 | 0 | 0 | 0 | 0 | 0 | 0
2130 | 17.62518428 | 1100 |  |  |  | -0.031544145 | 0.011048099 | -0.988593044 | -0.003275118 | 15.72918501 | 16.49961457 | 0.166390063 | 0 | 0 | 2.745386418 | 0 | 0 | 0 | 0 | 0.23892837
5740 | 35.654215 | 1150 |  |  |  | -0.050260417 | 0.0175 | -0.990039063 | -0.02226607 | 128.8507147 | 16.44697505 | 1.388550235 | 0 | 0 | 22.83746876 | 0 | 0 | 0 | 0 | 2.340520833
8000 | 49.45460105 | 1200 |  |  |  | -0.037352136 | 0.011056674 | -0.988777807 | -0.041106838 | 273.2136812 | 16.3638342 | 3.2653191 | 0 | 0 | 53.43321739 | 0 | 0 | 0 | 0 | 1.474940413
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

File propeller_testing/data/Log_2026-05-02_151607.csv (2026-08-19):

Time (s) | ESC signal (µs) | Servo 1 (µs) | Servo 2 (µs) | Servo 3 (µs) | AccX (g) | AccY (g) | AccZ (g) | Torque (N·m) | Thrust (gf) | Voltage (V) | Current (A) | Motor Electrical Speed (RPM) | Motor Optical Speed (RPM) | Electrical Power (W) | Mechanical Power (W) | Motor Efficiency (%) | Propeller Mech. Efficiency (gf/W) | Overall Efficiency (gf/W) | Vibration (g) | App message
0 | 1000 |  |  |  | 0 | 0.033203125 | -1 | -0.004109009953556498 | 95.84463127497628 | 16.52941131591797 | 0.087890625 | 0 | 0 | 1.4527802914381027 | 0 | 0 | 0 | 0 | 0.138671875
0 | 1000 |  |  |  | -0.03125 | 0.009765625 | -0.994140625 | -0.003931491731330689 | 108.27663045640843 | 16.53317642211914 | 0.030445771291851997 | 0 | 0 | 0.5033653080756793 | 0 | 0 | 0 | 0 | 0.13671875
0.0809999999999418 | 1000 |  |  |  | -0.025390625 | -0.005859375 | -1 | -0.005314744177847658 | 261.8621281627131 | 16.532285690307617 | 0.02511160634458065 | 0 | 0 | 0.41515225023114866 | 0 | 0 | 0 | 0 | 0.150390625
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

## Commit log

2026-08-02 Add result of uav sizing algorithm
    [design_Data.csv]
2026-08-02 Add cad render images and screenshots
2026-08-03 add cad files
    [Bottom_Plate.SLDDRW, Bottom_Plate.SLDPRT, Bottom_Plate.STEP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]
2026-08-03 add materials detail
2026-08-19 Propeller testing added
    [Final_Data.csv, Log_2026-05-02_151607.csv, Log_2026-05-02_151943.csv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]

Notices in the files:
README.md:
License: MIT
